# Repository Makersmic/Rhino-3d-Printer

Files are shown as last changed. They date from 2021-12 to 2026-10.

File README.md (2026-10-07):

<p align="center">
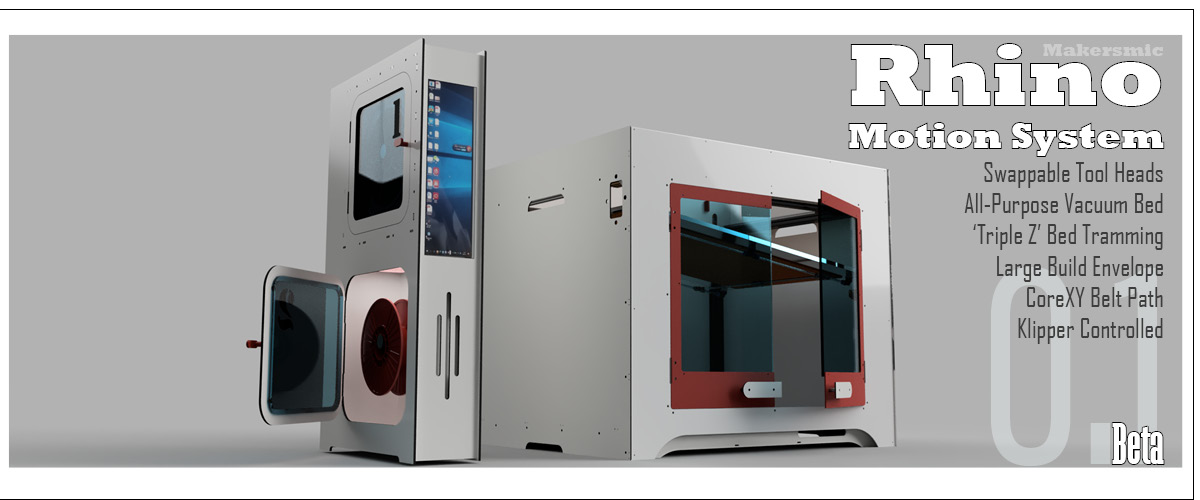
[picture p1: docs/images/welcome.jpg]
Rhino Motion System
  
</p>

<h1 align="center">Rhino Motion System</h1>

<p align="center">
  <b>An open-source, multi-tool CoreXY machine for 2D and 3D making.</b><br>
  One gantry, five swappable toolheads - 3D printing, laser, CNC spindle and drag knife - controlled by Klipper.
</p>

<p align="center">
  
  
  
  
</p>

<p align="center">
  <b>This repo:</b> the machine - CAD, drawings and build notes &nbsp;·&nbsp;
  <b><a href="https://github.com/Makersmic/Toolhead_Manager">Toolhead_Manager</a>:</b> the software - Klipper config, macros, portal and user manual
</p>

## The toolheads

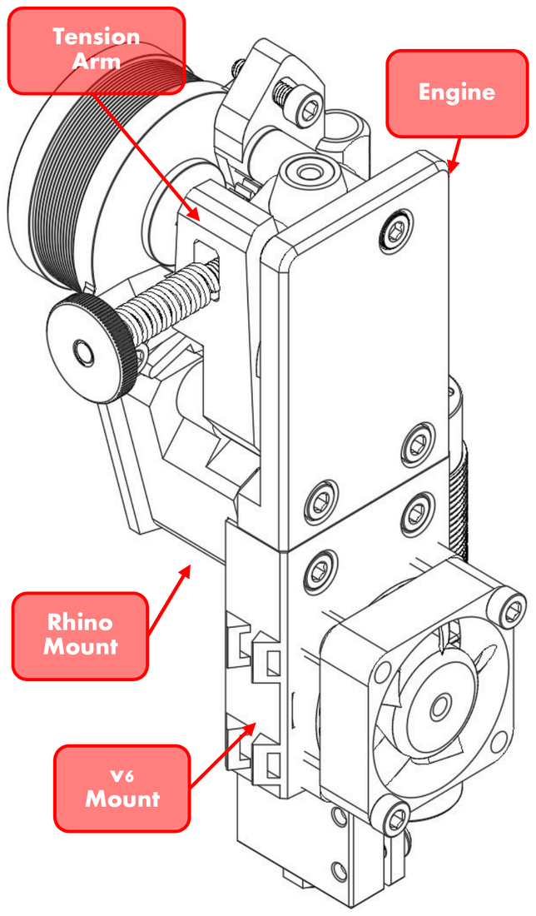
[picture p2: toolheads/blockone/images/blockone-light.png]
blockone
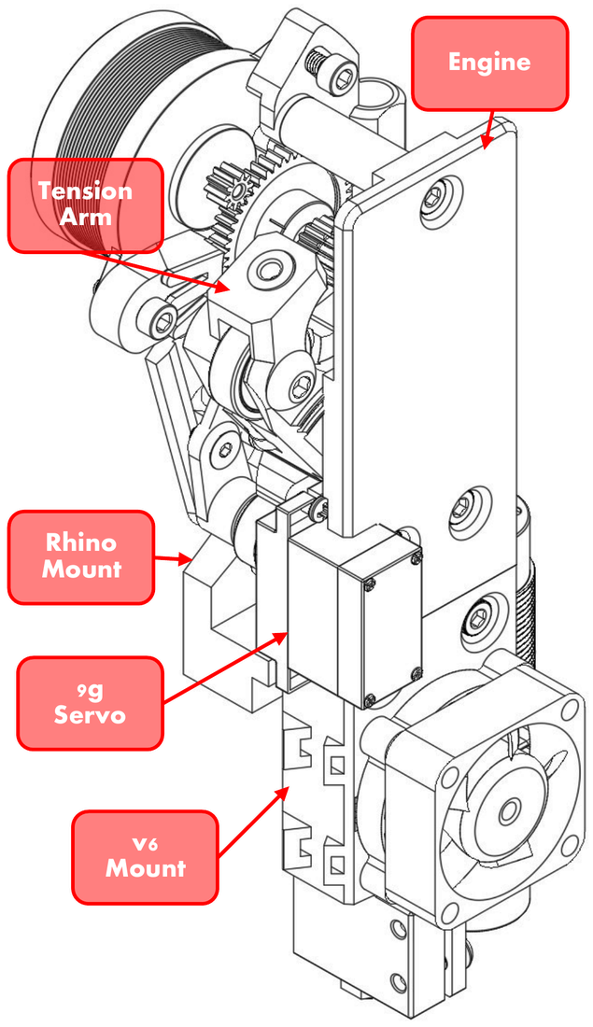
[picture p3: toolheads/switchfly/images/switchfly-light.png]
switchfly
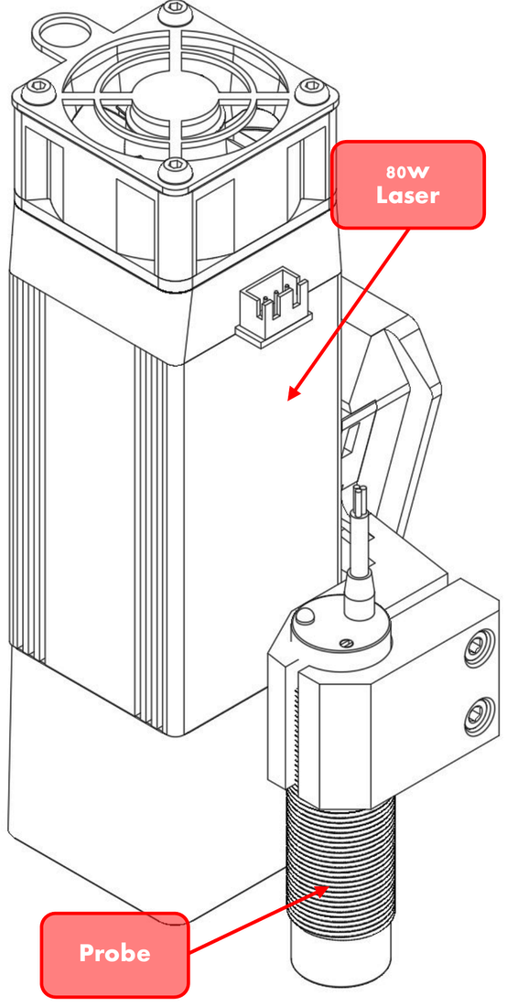
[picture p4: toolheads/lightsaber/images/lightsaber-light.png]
lightsaber
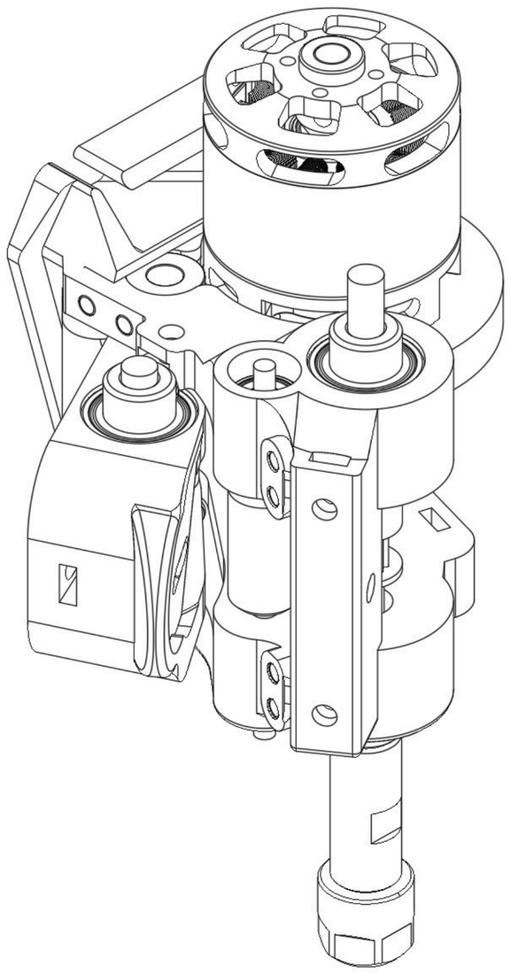
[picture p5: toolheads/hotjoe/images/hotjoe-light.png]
hotjoe
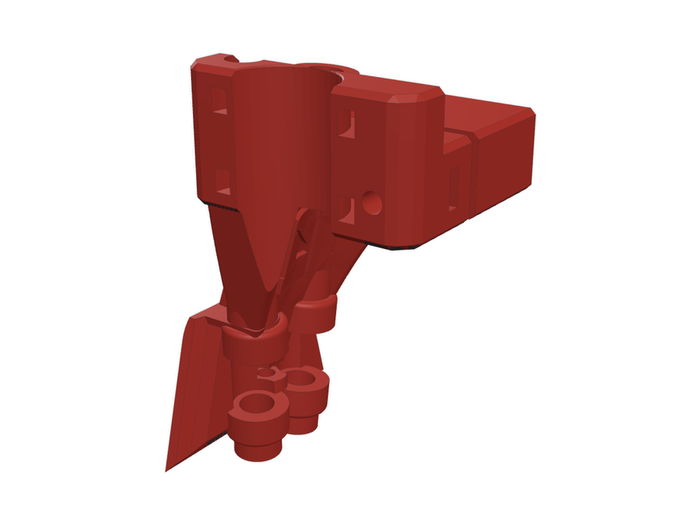
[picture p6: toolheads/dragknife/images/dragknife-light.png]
dragknife
<table align="center"><tr><td align="center"><a href="toolheads/blockone/"><picture><source media="(prefers-color-scheme: dark)" srcset="toolheads/blockone/images/blockone-dark.png"></picture></a></td><td align="center"><a href="toolheads/switchfly/"><picture><source media="(prefers-color-scheme: dark)" srcset="toolheads/switchfly/images/switchfly-dark.png"></picture></a></td><td align="center"><a href="toolheads/lightsaber/"><picture><source media="(prefers-color-scheme: dark)" srcset="toolheads/lightsaber/images/lightsaber-dark.png"></picture></a></td><td align="center"><a href="toolheads/hotjoe/"><picture><source media="(prefers-color-scheme: dark)" srcset="toolheads/hotjoe/images/hotjoe-dark.png"></picture></a></td><td align="center"><a href="toolheads/dragknife/"><picture><source media="(prefers-color-scheme: dark)" srcset="toolheads/dragknife/images/dragknife-dark.png"></picture></a></td></tr><tr><td align="center"><a href="toolheads/blockone/"><b>BlockOne</b></a><br><sub>3D printing</sub></td><td align="center"><a href="toolheads/switchfly/"><b>SwitchFly</b></a><br><sub>Dual extrusion</sub></td><td align="center"><a href="toolheads/lightsaber/"><b>LightSaber</b></a><br><sub>80 W laser</sub></td><td align="center"><a href="toolheads/hotjoe/"><b>HotJoe</b></a><br><sub>CNC spindle</sub></td><td align="center"><a href="toolheads/dragknife/"><b>DragKnife</b></a><br><sub>Drag knife</sub></td></tr></table>

Tools slot into a V-groove on the X-carriage and plug into a 21-pin umbilical at the back of the frame, so each tool
carries only the wiring it needs. [More about the toolheads and the umbilical &rarr;](toolheads/)

## Key features

- **Swappable toolheads** with one M3 bolt and a 21W4 umbilical connector
- **CoreXY with 15 mm belts** on X and Y, and the "Bulkup" XY joiners
- **Three-point Z** - three belt-driven leadscrews with kinematic couplings, trammed by Klipper
- **All-purpose vacuum bed** with air-gap insulated heated plate
- **Enclosed build chamber** with ACP panels and doors
- **Fresh air** - part cooling for printing, blow-air for the laser, chip clearing for the spindle
- **Klipper firmware** on a BTT Octopus, with DIN-rail relays for every heavy load
- **Tool Manager portal** - safe tool swaps, a page for every tool and maintenance tracking ([Toolhead_Manager](https://github.com/Makersmic/Toolhead_Manager))

<p align="center"><a href="https://github.com/Makersmic/Toolhead_Manager">Tool Manager dashboard</a><br>
<sub>The Tool Manager portal, from <a href="https://github.com/Makersmic/Toolhead_Manager">Toolhead_Manager</a></sub></p>

## What's in this repo

| Folder | What's there |
|---|---|
| [frame](frame/) | Frame assembly (2020/2040/2060 extrusion and flat bar), drawing, STEP; [panels](frame/panels/) - ACP enclosure, doors, front spacers |
| [motion/xy](motion/xy/) | XY joiners, [X-carriage](motion/xy/x-carriage/), stepper mounts, rear idler, belt tensioners, router templates |
| [motion/z](motion/z/) | Leadscrew carriages and Z stepper mounts |
| [bed](bed/) | Vacuum bed heat spreader |
| [toolheads](toolheads/) | [BlockOne](toolheads/blockone/), [SwitchFly](toolheads/switchfly/), [LightSaber](toolheads/lightsaber/), [HotJoe](toolheads/hotjoe/), [DragKnife](toolheads/dragknife/), and the legacy [Jack Rabbit](toolheads/jack-rabbit/) |
| [electrical](electrical/) | Controller, relays, distribution, umbilical and wiring diagrams |
| [filament-box](filament-box/) | "Cheeky Monkey" roll stand and runout switch (unfinished) |
| [docs](docs/) | [Software](docs/apps.md), [safety](docs/safety.md), [maintenance](docs/maintenance.md), [welcome page PDF](docs/rhino-welcome-page.pdf) |
| [archive](archive/) | 2023 firmware and app notes, kept for reference only |

**Software, config and the user manual** are in **[Toolhead_Manager](https://github.com/Makersmic/Toolhead_Manager)**: the Klipper/Mainsail config package
with a menu installer, the Tool Manager portal, OrcaSlicer profiles and the full user manual (PDF).

## Roadmap

- **BlockOne build files** - [folder ready](toolheads/blockone/)
- **SwitchFly build files**
- **Touch-probe Z setting** for the laser, spindle and drag knife
- **Kiri:Moto** for laser, drag-knife and CNC jobs from one interface
- **Project "Cheeky Monkey"** - a modular filament box: filament monitoring, air handling, chip exhaust, liquid cooling
- **Smoke detection** wired into Klipper ([safety](docs/safety.md))
- **Machine profiles** so other builders can use the Tool Manager on their own machines
- **Small build-farm management**

This is an ever-evolving project. Expect updates as parts are improved or corrected.

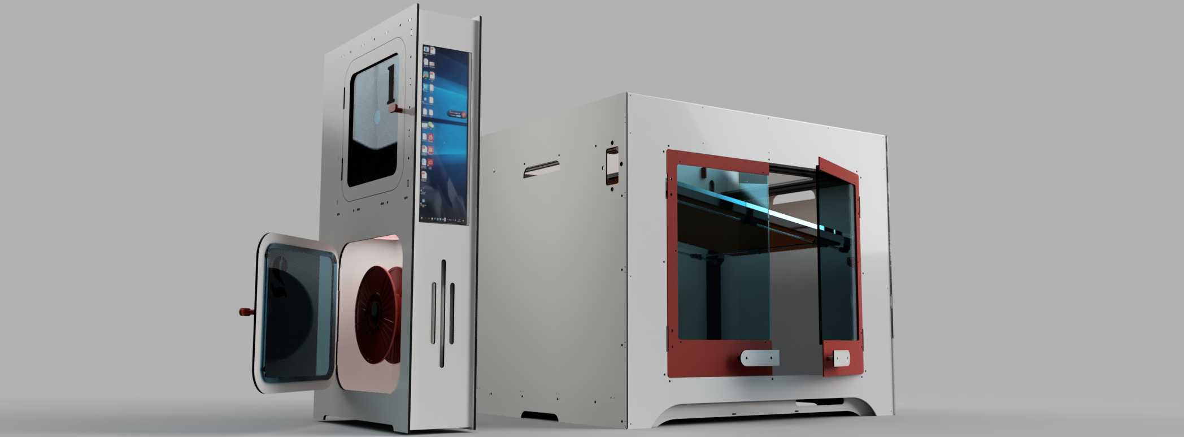
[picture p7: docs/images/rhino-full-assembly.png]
Rhino full assembly


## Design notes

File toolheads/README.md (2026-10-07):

# Toolheads

<table><tr><td align="center"><a href="blockone/"><picture><source media="(prefers-color-scheme: dark)" srcset="blockone/images/blockone-dark.png">blockone</picture></a></td><td align="center"><a href="switchfly/"><picture><source media="(prefers-color-scheme: dark)" srcset="switchfly/images/switchfly-dark.png">switchfly</picture></a></td><td align="center"><a href="lightsaber/"><picture><source media="(prefers-color-scheme: dark)" srcset="lightsaber/images/lightsaber-dark.png">lightsaber</picture></a></td><td align="center"><a href="hotjoe/"><picture><source media="(prefers-color-scheme: dark)" srcset="hotjoe/images/hotjoe-dark.png">hotjoe</picture></a></td><td align="center"><a href="dragknife/"><picture><source media="(prefers-color-scheme: dark)" srcset="dragknife/images/dragknife-dark.png">dragknife</picture></a></td></tr><tr><td align="center"><a href="blockone/"><b>BlockOne</b></a><br><sub>3D printing</sub></td><td align="center"><a href="switchfly/"><b>SwitchFly</b></a><br><sub>Dual-extrusion printing</sub></td><td align="center"><a href="lightsaber/"><b>LightSaber</b></a><br><sub>Laser</sub></td><td align="center"><a href="hotjoe/"><b>HotJoe</b></a><br><sub>CNC spindle</sub></td><td align="center"><a href="dragknife/"><b>DragKnife</b></a><br><sub>Drag knife</sub></td></tr></table>

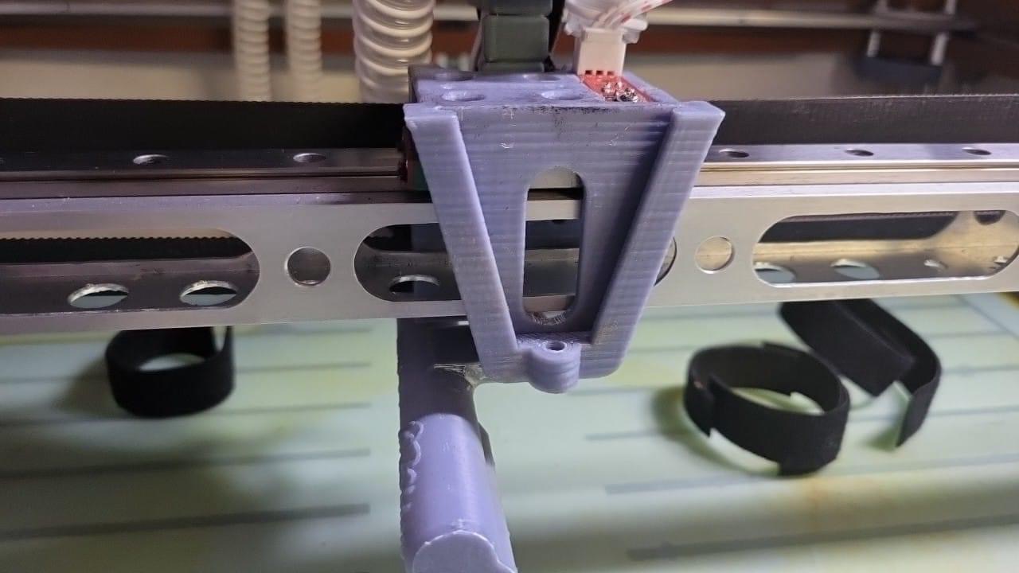
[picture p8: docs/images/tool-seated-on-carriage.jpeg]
A tool seated on the X-carriage


The Rhino uses swappable tools mounted to the X-carriage. A tool slides down into the V-groove on the front of the
carriage, which aligns it, and is held by one M3×50 bolt with a knurled nut (or wing nut).

| Slot | Tool | What it does | Folder |
|---|---|---|---|
| 1 | **BlockOne** | Single-extruder 3D printing (0.4 / 0.8 mm nozzles) | [blockone](blockone/) |
| 2 | **SwitchFly** | Two filaments, one stepper, one nozzle | [switchfly](switchfly/) |
| 3 | **LightSaber** | 80 W, 12 V blue diode laser - cutting and engraving | [lightsaber](lightsaber/) |
| 4 | **HotJoe** | 24 V brushless spindle with ER8 collet | [hotjoe](hotjoe/) |
| 5 | **DragKnife** | Passive drag knife for vinyl, cardstock, foam | [dragknife](dragknife/) |
| - | Jack Rabbit | Earlier print head, superseded by BlockOne | [jack-rabbit](jack-rabbit/) |

More tools (hot wire, needle cutter, pens, extra nozzle sizes) can be added from the
[Tool Manager](https://github.com/Makersmic/Toolhead_Manager) portal without editing config files.

## The umbilical and the Hub

Every tool ends in a male **21W4 D-sub** connector (four high-current contacts plus seventeen signal pins). The female
half is fixed at the top rear of the frame, with the **Hub** - a row of Wago-style terminal blocks - directly below it in
the cabinet. Because the mating point is at the rear, each tool carries only the wiring it needs.

| Contacts | Print heads | LightSaber | HotJoe | DragKnife |
|---|---|---|---|---|
| 1-2 | Hotend heater | - | - | - |
| 3-4 | Thermistor | Thermistor | Thermistor | Thermistor |
| 5-6 | Hotend fan | - | - | - |
| 7-10 | Extruder stepper | - | - | - |
| 11-12 | (SwitchFly: servo power) | - | 24 V power (relay) | - |
| 13-15 | Probe | Probe | Probe | Probe |
| 16-17 | - | Laser PWM | - | - |
| 18-19 | (SwitchFly: servo PWM) | - | Spindle PWM (ESC) | - |
| 20-21 | - | 12 V power (relay) | - | - |

**Constant connections** don't go through the umbilical; they run to the carriage through the Back Bone: X endstop
(3 wires), two 20 mm air tubes, the chamber thermistor and the LED strip.

### Why every tool has a thermistor

Klipper's extruder expects a temperature reading at all times. Rather than editing `printer.cfg` for every tool, each
tool carries the same thermistor type on contacts 3-4 (the laser's is on its heatsink). The swap wizard also reads it
to confirm the umbilical is seated.

## Swapping tools

Run `SWAP_TOOL` (a Mainsail button). It cools down, lowers the bed to a safe height, homes X/Y only - never Z with a
laser, spindle or knife on - and walks you through the swap with pop-ups. Sliced files name the tool they need, and a
job won't start if a different tool is mounted.

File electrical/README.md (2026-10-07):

# Electrical

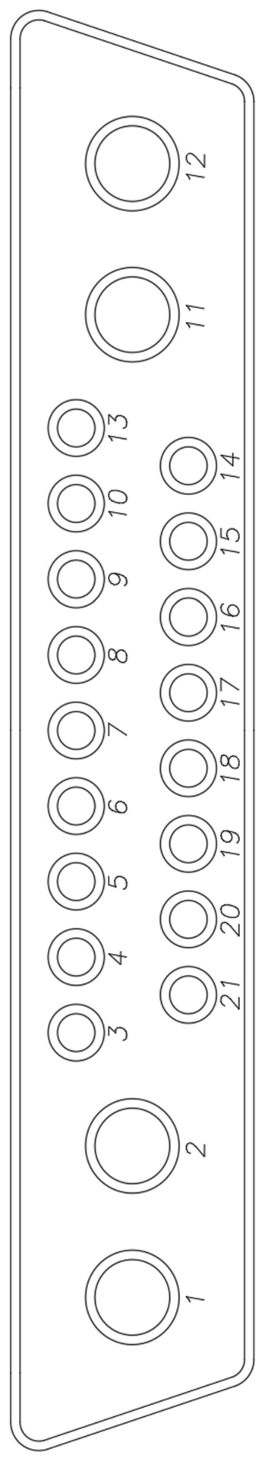
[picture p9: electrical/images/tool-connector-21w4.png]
21W4 connector
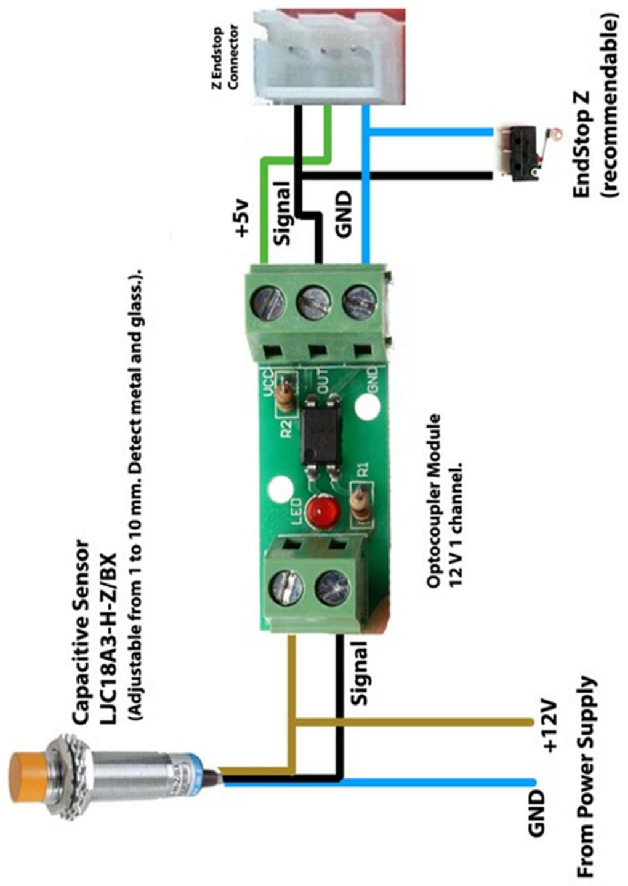
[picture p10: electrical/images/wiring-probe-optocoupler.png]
Probe wiring
<p align="center">&nbsp;&nbsp;</p>

## Controller

| Part | Current hardware |
|---|---|
| Mainboard | **BTT Octopus v1.1** (replaced the SKR GTR + M5 used in the 2023 build) |
| Klipper host | Raspberry Pi running Klipper, Moonraker and Mainsail |
| Power | Separate 24 V, 12 V and 5 V supplies |

The pin numbers for every tool are in the [toolhead pages](../toolheads/) and in the user manual in
[Toolhead_Manager](https://github.com/Makersmic/Toolhead_Manager). The old pin-assignment PDF for the GTR board has been removed.

## Relays

DIN-rail relays switch every heavy load, which keeps high currents off the board and makes a failed relay a quick
swap. Mechanical relays are easier to troubleshoot, and the click is reassuring; the heated bed mats use SSRs.

| Circuit | Relay |
|---|---|
| 12 V low current: LED and NeoPixel lighting, fans | 700-TBR24 6 A |
| 12 V high current: laser module, vacuum pump | JQX-13FL 10 A |
| 24 V high current: spindle (ESC power) | JQX-38F 40 A |
| Heated bed mats | Solid-state relays |

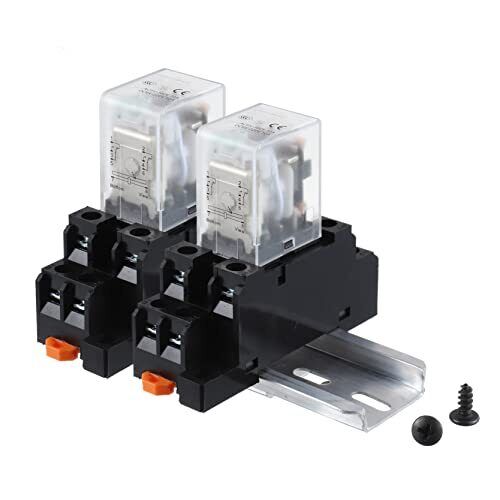
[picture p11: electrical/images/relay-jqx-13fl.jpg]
JQX-13FL relay
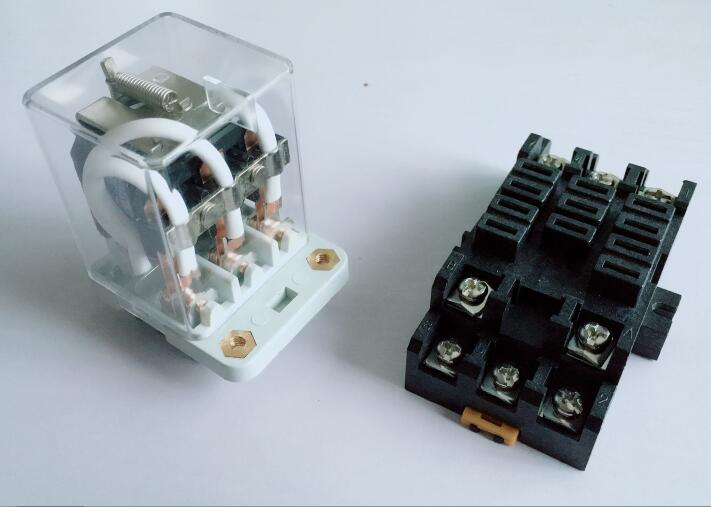
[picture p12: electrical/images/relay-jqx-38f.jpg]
JQX-38F relay


## Distribution and protection

- **Umbilical interface (the Hub):** Wago-style blocks that can't be bridged.
- **Power distribution:** traditional distribution blocks that can be bridged.
- **DIN-rail fuse holders:** protect the stepper motor lines against shorts.

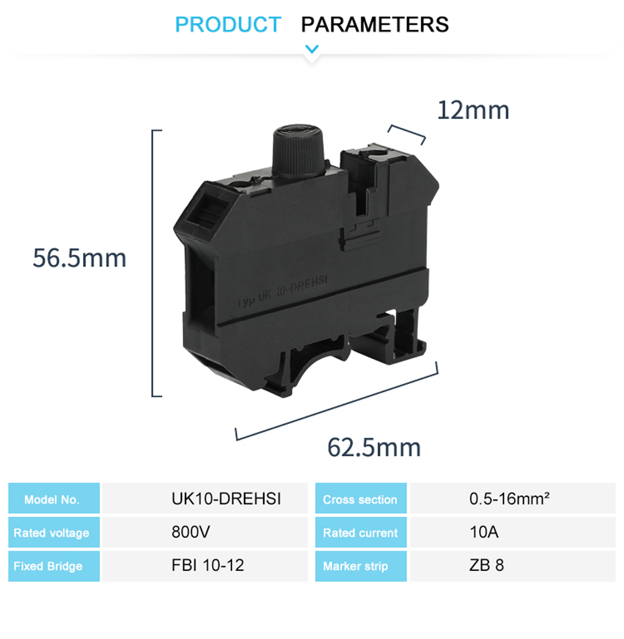
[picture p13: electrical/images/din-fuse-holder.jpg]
DIN-rail fuse holder
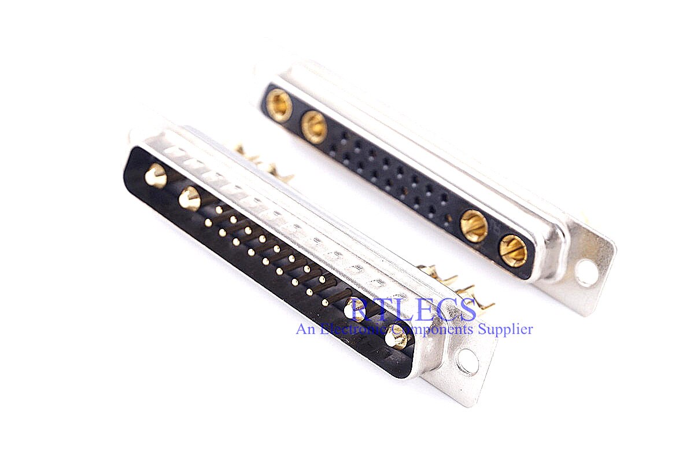
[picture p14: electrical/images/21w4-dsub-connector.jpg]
21W4 D-sub connector


## Umbilical

Male/female **21W4 D-sub** connectors; the cable is braided Cat5 plus two 14 AWG conductors. See
[toolheads](../toolheads/#the-umbilical-and-the-hub) for what each contact carries.

## Wiring diagrams

| Diagram | |
|---|---|
| Capacitive Z probe through the optocoupler (mounted in the cabinet) | [wiring-probe-optocoupler.png](images/wiring-probe-optocoupler.png) |
| 4-pin PWM fan | [wiring-4pin-fan.png](images/wiring-4pin-fan.png) |
| HotJoe ESC | [wiring-hotjoe-esc.png](images/wiring-hotjoe-esc.png) |
| SwitchFly servo | [wiring-switchfly-servo.png](images/wiring-switchfly-servo.png) |

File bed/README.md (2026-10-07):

# Vacuum bed

The Rhino's all-purpose vacuum bed. The heated build plate uses 'air gap' insulation: an open pocket of air between the
silicone heater mats and the cover on the underside.

| File | What it is |
|---|---|
| `Heat Spreader.step` | Bed heat spreader |

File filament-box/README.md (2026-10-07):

# Cheeky Monkey - the filament box

> **Unfinished design.**
An unfinished design, Cheeky Monkeys initial putpose was to provide monitoring and filament splices during 3d printing or other manufacturing procedures but was subsequently halted when the realization came that Cheeky Monkey needed to evolve into something much more in order to support future tool heads or manufacturing techniques.  
Cheeky Monkeys future goals will be to support 3d printing filament monitoring, an air handling system for high pressure blow air accessories and too heads, deep vacuum for chip removal and vacuum forming.

| File | What it is |
|---|---|
| `Roll Stand v5.step` | Filament roll stand |
| `Filament Runout Swich v5.step` | Filament runout switch |

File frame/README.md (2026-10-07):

## The Frame

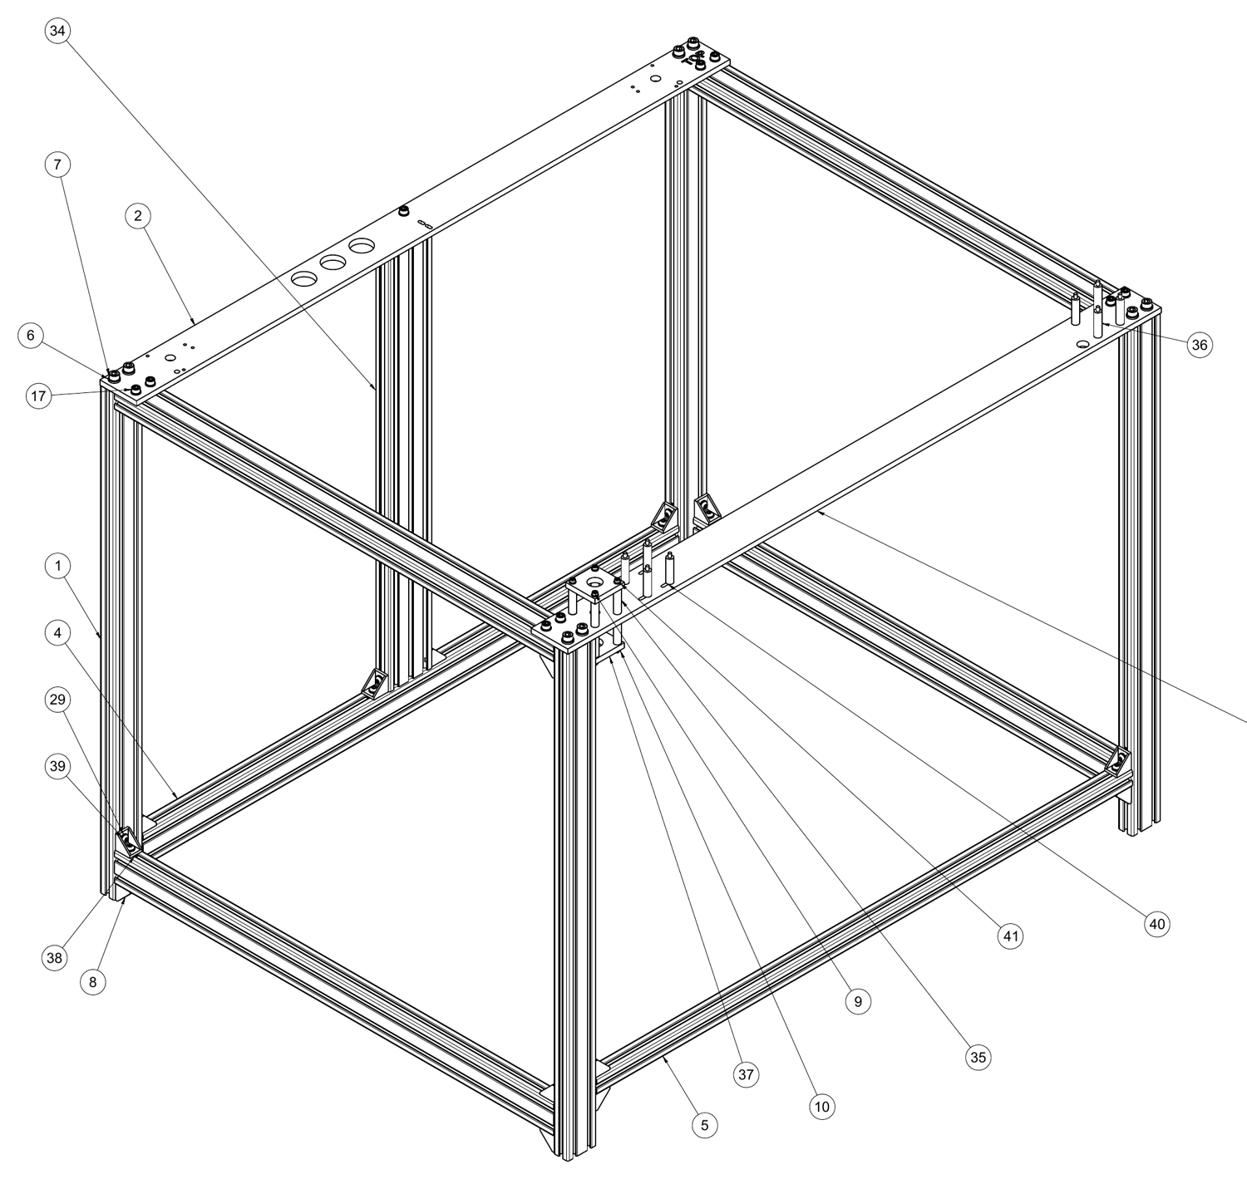
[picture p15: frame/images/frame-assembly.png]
Frame assembly

The Rhino utilizes aluminum extrusions based on the popular 2020, 2040, 2060 specification and 0.25" x 2" aluminum flat bar among other standard fasteners.  

### Designed for DIY
I took an uncommon approach with the aluminum flat bar components in the sense that you will find some components directly mounted to them.  To keep hole placement and 
other features accurate I have designed up 3d printable templates for hole placement and other features such as large pass-through cut-outs.  

Templates can be simply clamped to the workpiece and then a user may use a cordles drill or router for the appropriate feature.  When using a router, load a 0.375" 
flush trim bit with plenty of cutting fluid.  Also, due to possible excessive heat i recommend ABS as the material choice when 3d printing the templates.  Tutorial videos may be found on youtube of several people utuilizing a router for cutting aluminum.  It is recommeneded 
to watch a couple if you are unfamiliar with this technique.

### Parts List
Refer to `Frame Assembly Drawing v1.pdf` for a complete parts list of the frame and assembly reference.  

### Use socket-head bolts
Use Hex-Socket head style bolts, not Button head style bolts.  Button head style bolts have a greater tendancy to strip-out when being torqued down.

### Enclosure panels
3 mm ACP panels, doors and hinges, and the front spacer assembly are in [panels](panels/).

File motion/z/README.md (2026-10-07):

# Z axis

The bed rides on **three leadscrews** joined to the build plate by kinematic couplings: one **T12×2** at the rear and
two **T8×2** at the front. Each screw has its own stepper and is belt-driven through a **2:1 reduction** on closed-loop
2GT 15 mm belts (180–190 mm loop).

Klipper matches this with `gear_ratio: 2:1` on all three Z steppers (`stepper_z`, `stepper_z1`, `stepper_z2` in
`printer.cfg`). Because each corner has its own motor, Klipper trams the bed with `Z_TILT_ADJUST`.

Parts are in [leadscrew-based](leadscrew-based/).

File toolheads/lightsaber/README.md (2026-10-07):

# LightSaber

<p align="center"><picture><source media="(prefers-color-scheme: dark)" srcset="images/lightsaber-dark.png">lightsaber</picture></p>

**Laser cutting and engraving** · slot 3 in the Tool Manager

An 80 W, 12 V blue diode laser for cutting vector shapes from flat sheet and engraving. A relay switches its 12 V
supply (contacts 20-21) and Klipper drives its intensity (contacts 16-17). A thermistor on the heatsink keeps Klipper
happy and lets the swap wizard confirm the umbilical is seated. The printed **height gauge** sets the focus distance.

**Safety:** wear glasses rated for the laser's wavelength, run extraction, never cut PVC or vinyl, and stay with the
machine for the whole cut.

## Files

| File | What it is |
|---|---|
| `Laser Mount.step` | Mount that slots onto the X-carriage |
| `Height Gage.step` | Printed gauge for setting focus height |

## Tool connector (21W4)

Contacts this tool uses. Pins 1, 2, 11 and 12 are the high-current contacts. Full wiring: [electrical](../../electrical/).

| Contact | Use |
|---|---|
| 3 | Thermistor |
| 4 | Thermistor |
| 13 | Probe |
| 14 | Probe |
| 15 | Probe |
| 16 | Laser PWM (5 V) |
| 20 | + 12 V power activate |
| 21 | - 12 V power activate |

## Running it

- **Set up a job with:** `LASER_JOB_SETUP FILE=<name>.gcode`
- **Outputs in Klipper:** LASER_INITIALIZE 12 V rail, SERVO_LASER intensity
- **Macros:** `LASER_JOB_SETUP`, `LASERHOME`, `LASER_FOCUS_ALIGN`, `SET_LASER_POWER`, `ACTIVATE_LASER`, `DEACTIVATE_LASER`

Config, macros and the Tool Manager portal live in **[Toolhead_Manager](https://github.com/Makersmic/Toolhead_Manager)**; the user manual there has a full chapter on each tool.

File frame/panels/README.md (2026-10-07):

## Panels
Panels are to be constructed using material 3mm in thickness, ACP is the recommended material choice.

| Folder | What's there |
|---|---|
| (this folder) | Inner and outer panels, control panel, side panels |
| [door-hardware](door-hardware/) | Doors, hinges and hinge pin |
| [front-spacer-assembly](front-spacer-assembly/) | Front spacers, corner bracket and drawing |

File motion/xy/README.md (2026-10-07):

# The Gantry
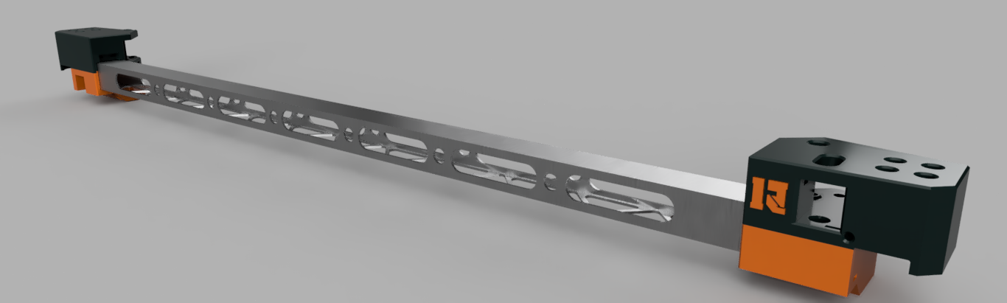
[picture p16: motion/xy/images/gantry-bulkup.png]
Rhino Motion System


## XY Motion System
Optimized for 15mm belts, the files found within this section will enable you to construct the xy motion system.  As a bonus I've uploaded step files to make editing for modifications easier for the community.

### DIY Aluminum Gantry Frame
The x-axis frame piece is constructed using 1" aluminum square tube with a wall thickness of 1/16".  Cutouts are made using 3d printed router templates.  Templates and how to use them: [gantry-router-templates.md](gantry-router-templates.md).
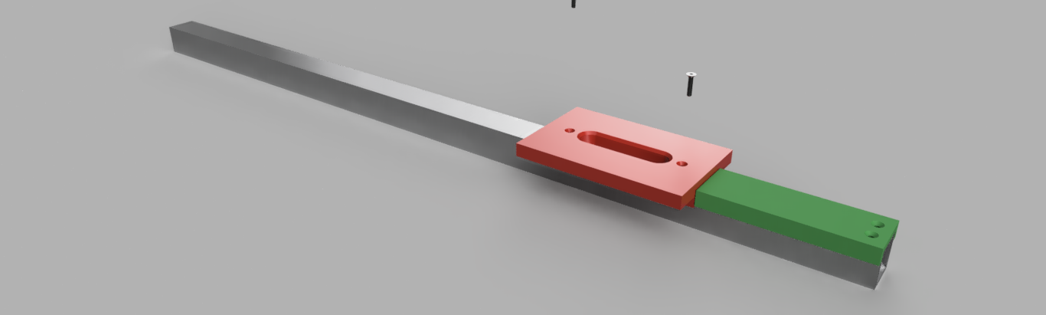
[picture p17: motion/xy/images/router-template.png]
Rhino Motion System


### Why 15mm belts?
Because of the tools that can be used with the Rhino motion system, I felt it best to go with some hefty belts.  In additional to a longer duty cycle benefits of these larger belts would include less resonance 
on the gantry which translates to higher quality 3d prints, smoother cuts when using the laser or spindle modules, and a quieter printer.

### How long should the belts be?
3 meters for each belt run, so 6 meters total will be needed.  It is also recommended to utilize dust-proof glass fiber core belts.

### Change History - new section
04-14-2023 - Uploaded a new design for the xy joiners, a design that I refer to as "The Bulkup Concept".  This came about after i began to notice sagging in previous design where the x-axis frame and xy joiner meet.  In addition I added extra material to the areas that contain the pulleys to account for excessive strain during belt tensioning.  This design has been tested for 3 months and is proving effective.

## In this folder

| Folder | What's there |
|---|---|
| (this folder) | XY joiners (left/right, top/bottom), Y endstop flag |
| [x-carriage](x-carriage/) | Carriage, Back Bone mount and bearing spacer |
| [stepper-mounts](stepper-mounts/) | A/B stepper mounts and Torque Buddy |
| [rear-center-idler](rear-center-idler/) | 15 mm rear centre idler and drawing |
| [belt-tensioner](belt-tensioner/) | Belt tensioner, cam and knob assemblies with drawings |

<p align="center">Gantry</p>

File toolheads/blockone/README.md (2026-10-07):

# BlockOne

<p align="center"><picture><source media="(prefers-color-scheme: dark)" srcset="images/blockone-dark.png">blockone</picture></p>

**3D printing - single extruder** · slot 1 in the Tool Manager

BlockOne is the Rhino's single-extruder print head and the updated version of the
[Jack Rabbit](../jack-rabbit/). It uses an E3D v6 Volcano hotend at 24 V with a BMG drive gear for 1.75 mm filament,
with OrcaSlicer profiles for 0.4 mm and 0.8 mm nozzles. Part cooling comes from the Rhino's universal blow-air system.

## Files

> **Build files coming soon.** This folder is ready for BlockOne's STEP/STL files and drawings - upload them here.
> Until then, the [Jack Rabbit](../jack-rabbit/) files show the earlier design.

## Tool connector (21W4)

Contacts this tool uses. Pins 1, 2, 11 and 12 are the high-current contacts. Full wiring: [electrical](../../electrical/).

| Contact | Use |
|---|---|
| 1 | 24 V hotend |
| 2 | 24 V hotend |
| 3 | Thermistor |
| 4 | Thermistor |
| 5 | 24 V hotend fan |
| 6 | 24 V hotend fan |
| 7 | Stepper |
| 8 | Stepper |
| 9 | Stepper |
| 10 | Stepper |
| 13 | Probe |
| 14 | Probe |
| 15 | Probe |

## Running it

- **Set up a job with:** `Slicer start G-code (START_JOB)`
- **Outputs in Klipper:** Hotend heater, hotend fan, part-cooling fan
- **Macros:** `NOZZLE_HEIGHT_CALIBRATE`, `PRIME_LINE`, `PURGE`, `FILAMENT_CHANGE`, `CALCULATE_PA`

Config, macros and the Tool Manager portal live in **[Toolhead_Manager](https://github.com/Makersmic/Toolhead_Manager)**; the user manual there has a full chapter on each tool.

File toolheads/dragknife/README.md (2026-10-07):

# DragKnife

<p align="center"><picture><source media="(prefers-color-scheme: dark)" srcset="images/dragknife-dark.png">dragknife</picture></p>

**Drag-knife cutting - vinyl, cardstock, thin foam** · slot 5 in the Tool Manager

A passive tool (formerly *Ostrich*) for Roland No. 9 and No. 10 blade holders. It has no power output: cut depth
comes from the blade dial and the Z zero set in the job wizard.

## Files

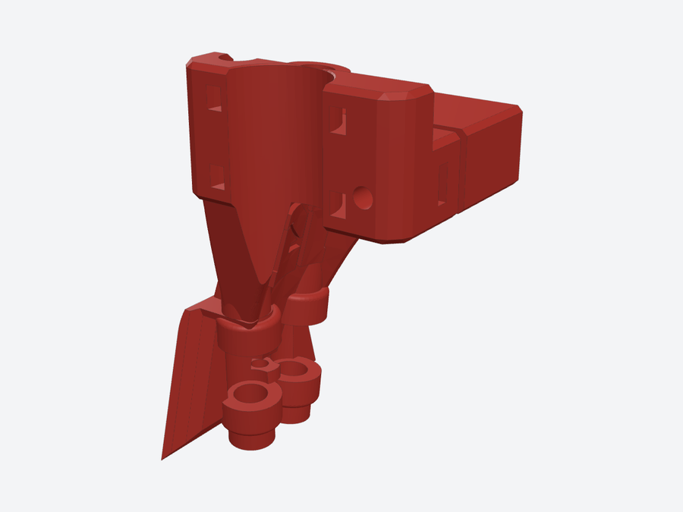
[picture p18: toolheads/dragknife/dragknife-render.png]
DragKnife render


| File | What it is |
|---|---|
| `Ostrich Drag Knife.step` | Drag-knife holder |

## Tool connector (21W4)

Contacts this tool uses. Pins 1, 2, 11 and 12 are the high-current contacts. Full wiring: [electrical](../../electrical/).

| Contact | Use |
|---|---|
| 3 | Thermistor |
| 4 | Thermistor |
| 13 | Probe |
| 14 | Probe |
| 15 | Probe |

## Running it

- **Set up a job with:** `DRAGKNIFE_JOB_SETUP FILE=<name>.gcode`
- **Outputs in Klipper:** None (passive tool)
- **Macros:** `DRAGKNIFE_JOB_SETUP`

Config, macros and the Tool Manager portal live in **[Toolhead_Manager](https://github.com/Makersmic/Toolhead_Manager)**; the user manual there has a full chapter on each tool.

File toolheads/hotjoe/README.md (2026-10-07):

# HotJoe

<p align="center"><picture><source media="(prefers-color-scheme: dark)" srcset="images/hotjoe-dark.png">hotjoe</picture></p>

**CNC spindle - light engraving and milling** · slot 4 in the Tool Manager

A brushless motor (2814, 1000 kV) with an ER8 collet, driven by an 80 A HobbyWing ESC on 24 V. A 40 A relay
powers the ESC only while the spindle is in use; the speed signal runs at 400 Hz. Intended for light-duty work -
check real speeds at the collet with a tachometer before relying on them, and calibrate the ESC once with
`CALIBRATE_ESC`.

## Files

| File | What it is |
|---|---|
| `Spindle Assembly.step` | Complete spindle assembly |
| `Spindle Main Body.step`, `Main Body Mount Clip v2.step`, `Spindle Carriage Mount Clip.step` | Body and carriage mounting |
| `Tensioner Body.step`, `Tension Arm Shield.stl` | Belt drive tensioner |
| `Motor Shield.step`, `Gearbox Shield.step` | Safety covers |
| `70mm cnc brush holder.step` | Brush skirt for dust collection |
| `Blow Air Clip v1.step`, `turbine.stl` | Blow-air nozzle |

## Tool connector (21W4)

Contacts this tool uses. Pins 1, 2, 11 and 12 are the high-current contacts. Full wiring: [electrical](../../electrical/).

| Contact | Use |
|---|---|
| 3 | Thermistor |
| 4 | Thermistor |
| 11 | 24 V relay power |
| 12 | 24 V relay power |
| 13 | Probe |
| 14 | Probe |
| 15 | Probe |
| 18 | PWM |

## Running it

- **Set up a job with:** `CNC_JOB_SETUP FILE=<name>.gcode`
- **Outputs in Klipper:** Spindle_power relay, SPINDLE_SPEED ESC signal
- **Macros:** `CNC_JOB_SETUP`, `SET_WORK_ZERO`, `PROBE_Z_WORK_ZERO`, `G54`, `Spindle_ACTIVATE`, `Spindle_DEACTIVATE`, `CALIBRATE_ESC`

Config, macros and the Tool Manager portal live in **[Toolhead_Manager](https://github.com/Makersmic/Toolhead_Manager)**; the user manual there has a full chapter on each tool.

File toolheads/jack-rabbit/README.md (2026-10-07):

# Jack Rabbit (legacy)

> **Outdated - superseded by [BlockOne](../blockone/).** Kept for reference and for anyone who built one.

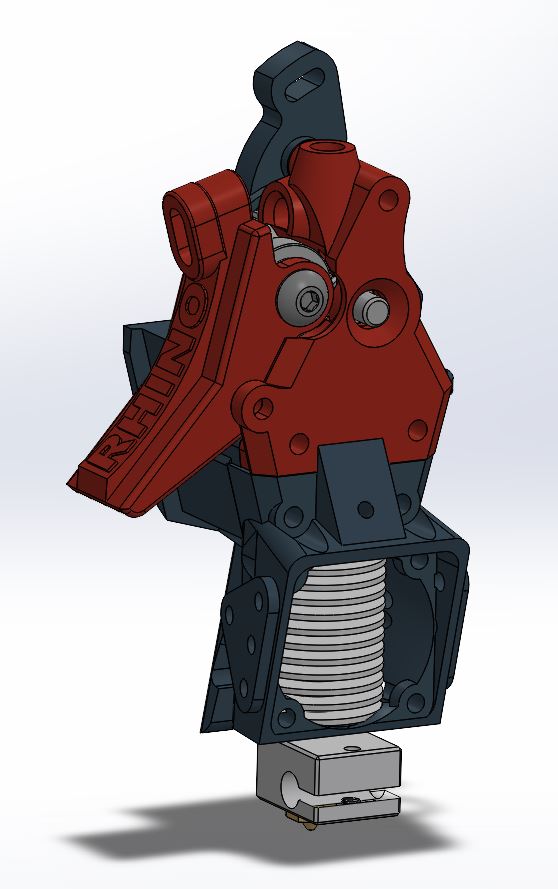
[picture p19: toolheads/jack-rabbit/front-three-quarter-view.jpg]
Jack Rabbit


## Lightweight direct-drive 3D printing tool head
The Jack Rabbit utilizes the large drive gear and a single famous 'BMG' gear in combination with a 625zz bearing to feed filament to the nozzle.  Gears are driven by round body style nema 14 stepper motor with a 10 tooth gear.  Print speeds can be had at 200mm in conjunction with an E3D v6 volcano hotend.  

## Key features
- Lightweight
- 5:1 gear ratio
- Squeeze-trigger release for easier one-handed operation
- Part cooling from a 40 mm double delta fan

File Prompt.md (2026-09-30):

📂 MASTER SPECIFICATION: THE RHINO MULTI-TOOL ECOSYSTEM
🤖 System Introduction & Context
This file serves as the definitive architecture manual and "State of the Machine" baseline for The Rhino—a heavily customized, modular 5-axis hybrid manufacturing workspace powered by Klipper, Moonraker, and an OrcaSlicer frontend. This machine utilizes a shared coordinate rail system but completely switches disciplines based on the physically attached toolhead via a manual, hot-swappable 21-pin umbilical connection line.
🗺️ Stored Global Mappings (variables.cfg)
All macros are explicitly aligned to a single, persistent disk cache file (variables.cfg) via Klipper’s [save_variables] module to prevent volatile dual-tracking sync lag across machine boots:
• Tool Registries: Stored inside a dictionary variable named tool_mapping mapping indexes (0 to 4) to names (BlockOne, SwitchFly, LightSaber, HotJoe, DragKnife).
• Active Hardware Position Tracker: The wizard uses printer["gcode_macro SWAP_TOOL"].current_tool to track what is physically connected to the machine.
• Workspace Transformations: Persistent CNC registers (cnc_g54_x, cnc_g54_y, cnc_g54_z) store offsets for subtractive tasks, safely isolating industrial coordinate shifts from default 3D print endstops.
🔧 Active Toolhead Modules & Software Rules
1. BlockOne (Slot 0)
• Type: DEPOSITION
• Configuration: Standard single-extruder 3D printing toolhead. Starts execution by passing explicit formatting via OrcaSlicer: START_JOB TOOLHEAD="BlockOne" MATERIAL="[filament_type]" NOZZLE_SIZE=[nozzle_diameter] EXTRUDER=0. Numbers are cleanly passed un-quoted to ensure stepper current arithmetic checks parse flawlessly.
2. SwitchFly (Slot 1)
• Type: DEPOSITION
• Configuration: Single physical stepper motor shared between two independent filament tubes. Alignments are shifted using a dedicated _SWITCHFLY_SET_PATH servo flag (0 to 180 degrees).
• The Direction-Reversal Override: Because path 1 pulls filament from the backside of the drive gears, G0 and G1 are globally intercepted using rawparams. If SwitchFly path 1 is active, extrusion targets are dynamically inverted to a negative orientation (E * -1.0) on the fly, safely preserving all travel tracking, layer speeds, and slicer width strings.
3. LightSaber (Slot 2)
• Type: LASER
• Configuration: High-frequency laser diode cutter. Integrates standard GRBL convention parameters (M3/M4/M5) scaled smoothly against laser_s_max.
• Safety Lockout: Implements hard hardware-gated overrides inside SET_LASER_POWER. If any job streams an M3 signal while a 3D printer hotend or spindle is attached, Klipper forces an immediate safety shutdown to protect the umbilical pins and user workspace. Isolates LEDFLASH from high-frequency lines to eliminate processor stutter. Features an interactive 1% duty-cycle visibility target utility (LASER_FOCUS_ALIGN).
4. HotJoe (Slot 3)
• Type: CNC
• Configuration: Brushless outrunner CNC spindle motor driven by a 400Hz open-loop RC Electronic Speed Controller (ESC). Low-endpoint throttle arms at 0.3, scaling to high-endpoint maximum thresholds at 1.0.
• Subtractive Calibration: Houses an interactive, graphical windowed CALIBRATE_ESC endpoints synchronization wizard. Integrates G54 offsets and an automated PROBE_Z_WORK_ZERO 10mm aluminum touch-plate downward search matrix.
5. DragKnife (Slot 4)
• Type: DRAG_KNIFE
• Configuration: Mechanical spring-loaded vector vinyl plotting blade. Features a dedicated, safety-gated absolute scoring utility (_DK_TEST_CUT) which drops exactly 0.3mm beneath the G54-zero material face to trace a 10mm validation cut line, protecting underlying cutting mats from relative plunge errors.
🖥️ Graphic User Experience Panels (Mainsail UI)
• SWAP_TOOL: A modular 2-stage hot-swap wizard. Shuts down heaters, cools gantry items to a safe 40°C, cuts extruder power lines to prevent pin-arcing, and pauses execution (PAUSE_BASE). It prompts the physical hand-swap before allowing verification hooks (CONFIRM_TOOL_INSTALL) to read the universal PF4 thermistor circuit line.
• PREHEAT: A dynamic pre-flight checker. If a sliced job specifies PLA, it halts execution and opens a web-interface modal allowing the operator to click a button and completely bypass build plate heating/soaking, leaping straight into the file.
• CNC_JOB_SETUP: A sequential step-by-step setup screen for machining. Guides workholding clamps, collet torque, and launches an optional dynamic choice path between touch-plate or manual paper zeroing.
• BACKUP_CONFIG: Automatically hooks into CONFIRM_TOOL_INSTALL and any successful print job that tracks an execution runtime greater than 2 hours (printer.print_stats.total_duration >= 7200). Packages and pushes the entire .cfg layout tree, macro sets, and uploaded OrcaSlicer .bb bundles straight to your remote GitHub repo over an authenticated secure SSH key tunnel (git_protocol="ssh").

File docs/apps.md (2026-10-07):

# Software

I use free applications wherever possible - licence fees limit development and hurt community growth.

| Job | Software | Notes |
|---|---|---|
| Firmware and control | **Klipper + Moonraker + Mainsail** | Config, macros and the Tool Manager portal are in [Toolhead_Manager](https://github.com/Makersmic/Toolhead_Manager) |
| 3D printing (BlockOne, SwitchFly) | **OrcaSlicer** | Ready-made BlockOne profiles: [`slicer/orca`](https://github.com/Makersmic/Toolhead_Manager/tree/main/slicer/orca). The start G-code calls `START_JOB TOOLHEAD=BlockOne ...` |
| Laser, drag knife, CNC | **Kiri:Moto** (planned) | Free, open-source, browser-based; covers laser, drag knife and CNC in one interface |
| Laser (2023 workflow) | LaserWeb 4 | Old setup notes kept in [archive/2023-apps](../archive/2023-apps/laserweb-setup.md) |

Laser, spindle and drag-knife jobs are started with `LASER_JOB_SETUP`, `CNC_JOB_SETUP` or `DRAGKNIFE_JOB_SETUP`
`FILE=<name>.gcode`, which check the mounted tool and walk through zeroing before the file runs.

## Other useful software

- [Inkscape](https://inkscape.org/) - vector artwork for laser and knife
- [Tinkercad](https://www.tinkercad.com/) - quick 3D models
- [Zamzar](https://www.zamzar.com/) - file conversion

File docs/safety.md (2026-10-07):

# Safety

> **In place today** (in [Toolhead_Manager](https://github.com/Makersmic/Toolhead_Manager)): tools are only swapped once the hotend and bed are below 40 °C, Z is
> never homed with a laser, spindle or knife mounted, a job won't start if the wrong tool is mounted, every tool output is
> switched off on cancel, swap or emergency stop, and added powered tools have a power cap and a watchdog timer. The smoke-detection system below is still **planned**.

## Introduction
When people in the 3d printing talk about saftey there seems to be a universal concern, fire.  In terms of the Rhino though i wanted to expand this subject out more due to the 
multiple tools that can be utilized and the change procedures revolving around those tools.  

To address fire safety i want to install smoke alarms with relays.  The purpose of the smoke alarm having a relay is that the relay can be tied into the endstop inputs of the control 
board, thus making Rhino aware of when smoke/fire occurs and further more enabling Rhino to take action.

### Smoke Detection Module:
MQ-2.....Aliexpress $10

This smoke detector can operate on 12v or 24v and is small in size,49x45x20mm

The BTT Octopus has spare endstop inputs available for these. (The 2023 notes counted inputs on the old SKR GTR + M5.)

In addition to the smoke detection modules, the printer must have 110v and 220v relays that are tied into the power supplies of the printer.  Without these killing power to the
control board or other components will not be possible.  It may also be needed to run secondary mcu to support fire protocols when the printer has been powered off.  To
take a step further i can even see this secondary mcu having it's own power source that is not tied into mains power but rathe run from a rechargeable battery pack that is constantly
charged.  Utilizing 18650 batteries in a battery pack of some kind could be an avenue traveled for this aspect.

## Anticipated zones for smoke and fire:
-Build Chamber-This sensor will be located in the lid.

-Control Cabinet-These sensors one on each side will be mounted on the same din rails as the other components.  One for each side so a total of 2 sensors, will be mounted in the middle of top
din rail.

-Build Plate-Rhino utilizes 'air gap' insulation for the heated build plate.  The open pocket of air between the silicone heated mats and the cover located on the bottom side of the plate there is clearance to be able to install a smoke detector.

-Power Supply/Power Distribution Area-This sensor would be located in the area within close proximity to the power supplies and the bank of terminal blocks acting as power 
distribution.

## Actions
The macro that is written needs to do a couple things to ensure the long life of our printer:
-Immediately or almost immediately killing power to the 3d printer.

-Storing the last position of the print head much like that of when the printer is paused.

-Informing the user that smoke has been detected though the main display, or possibly tying it into telegram bot so a user can get messages sent directly to a device that they keep on their person.

In retrospect, all of the actions described above will come with conditions, or perhaps not triggered until a requirement is met or not met.

This subject needs to be expanded upon.

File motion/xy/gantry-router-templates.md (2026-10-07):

# Gantry Router Template Usage Guide
This document is to outline the usage of the router templates used to create the cutouts found on the x-axis aluminum frame piece.

### Materials Needed
1 3d printed router template

1 3d printed drill template

1pc 1" x 36" aluminum square tube, 0.0625" wall thickness

2pc m3 x 14mm Flathead bolt

Cutting Fluid

### Tools Needed
1 Power Drill

1 Palm Router(or router of your choice

1 0.375" Diameter Flush Trim Bit(2 Flute)

1 m3 tap

1 2.8mm drill bit

1 0.4375" drill bit

Various clamps for work staging

### How-to
1.  Start by placing the 3d printed drill template as shown.  Ensure that the side surface of the template is flush against the surface of the aluminum square tube.
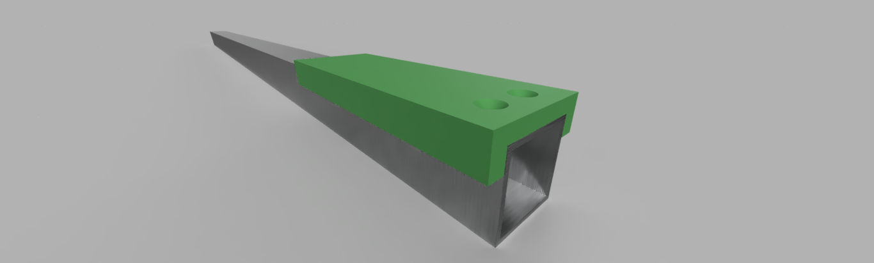
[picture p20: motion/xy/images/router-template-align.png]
Rhino Motion System


2.  Using a center punch, mark each end of the square tube using the template for placement of the center punch.  Each end of the square tube should have two markings for through-holes.
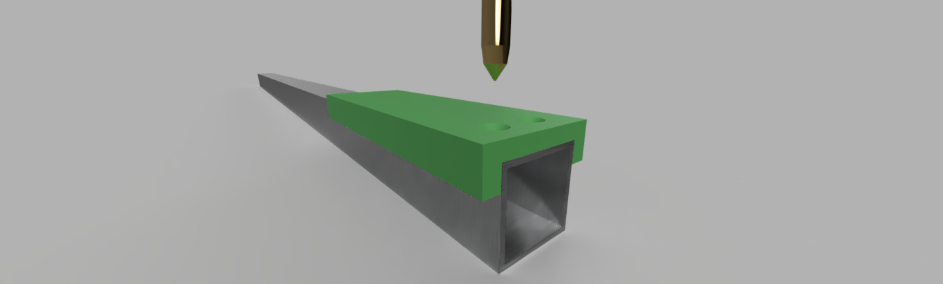
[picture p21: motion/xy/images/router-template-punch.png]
Rhino Motion System


3.  Remove the 3d printed drill template and drill each hole completely through the square tube using a 3.5mm drill bit.  It is recommended to use a drillpress when drilling these holes to ensure proper alignment.
4.  Wipe down or blow off all chip accumalations from drilling procedure.
5.  Install 3d printed router template as shown.
Rhino Motion System

6.  Mark first and second hole with center punch.
7.  Drill a hole in the cutout area using the 0.4375" drill bit.  This will be the **starting position** of where the router will begin cutting.
8.  Drill and tap first and second holes for m3 size bolt.
9.  Wipe down or blow off all chip accumalations from drilling procedure.
10.  Align the 3d printed router template to second cutout feature by means of aligning first hole of template to the second tapped hole of the aluminum square.

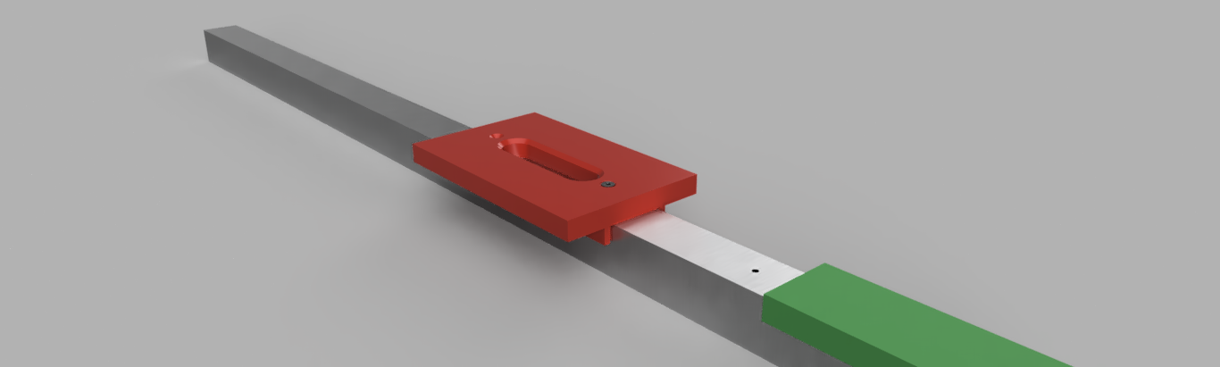
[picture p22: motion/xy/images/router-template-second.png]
Rhino Motion System


11. Secure template in place by installing an m3 flathead bolt in first alignment hole.
12.  Drill and tap second hole of template into aluminum square tube  with m3 tap.
13.  Wipe down and blow off all chip accumalations drom drilling procedure.
14.  Install second flathead bolt into second alignment hole.
15.  Repeat steps 9-14 until all cutouts have been recognized.
16   Ensure 3d printed router template in place by ensuring that the template is held in place by means of the 2 m3 flathead bolts installed into the template and square tube.
17.  With the power cord disconnected, set the depth of the 0.375" router bit to a cut depth of approximately 1/32".  
18.  Ensure cutting fluid has been applied to router bit and to the area of the square tube that will cut into by the router.
19.  With the router bit secured in the router and the cutting depth, place the router on top of the template in such a way that the router bit is in the center of the **starting position** hole.
20.  With a firm grasp on the router, power on the tool.
21.  Moving the router slowly, follow the templates cutout edge with bearing of the flush trim bit.
22.  When cut pass has been completed power off router and clear cutting area of debris.
23.  Move router template to next set of alignment holes and secure in place by means of flathead m3 bolts.
24.  Repeat steps 16-24 until all cutouts

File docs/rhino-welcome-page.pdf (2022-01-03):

Welcome to the Rhino Multi-Tool Manufacturing system, your partner in creativity. Thank you for choosing us!

When we were developing the Rhino we had a couple goals we wanted to target:

Ease of use-We wanted a machine that was not only easy to work with but easy to adjust when maintenance was due. We think this was achieved through our unique belt tensioning system and the standardization of various aspects throughout the machine. Rather than shy away from maintenance, we embrace and realize it is a part of well maintained machine.

Swappable Tools-To achieve the ability for Rhino to have interchangable tools we developed a tool swapping system focused around semi to long-term projects. We recognize that sometimes a user will want to focus on one aspect of the build process to achieve a desired result. Your not going to find super fancy or overly complex toolchanging systems with the Rhino, it’s a click n pop and it’s off.

Enclosed Build Chamber-Safety-wise an enclosed build chamber makes sense, no chance of Fido accidentally plunging his hand into the build area with walls to safely protect things. The natural biproduct of the enclosed build chamber, more consistent ambient temperatures, or with the added chamber heater, elevated build chamber temperatures lends themselves to a higher quality print print.

Expandability-This is an open source project, meaning that if a person wanted to they could develop their own tools for the Rhino. We’ve left the door wide open for development whether it’s through the open design or the open source firmware(Klipper) that is used to control Rhino.

Fun-We said it, and we know it’s corny ....but. It’s a fun system. Use it to create works ranging in such an array of brilliant materials, or do like a lot and tinker away with it.

# Multi-Tool

# Motion System

# Rhino

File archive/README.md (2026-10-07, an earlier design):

# Archive

Old files kept for reference. **Don't use these on a current Rhino** - the current config, macros and portal are in
[Toolhead_Manager](https://github.com/Makersmic/Toolhead_Manager).

| Folder / file | What it is |
|---|---|
| [2023-firmware](2023-firmware/) | Klipper configs and macros from the 2023 build (SKR GTR + M5 board, Jack Rabbit era): per-tool configs, M600, tooling ID, ESC, 4-pin fan and heated-bed notes |
| [2023-apps](2023-apps/) | LaserWeb 4 setup notes |
| [2026-09-ai-spec.md](2026-09-ai-spec.md) | An AI briefing written in Sept 2026. **Outdated:** it numbers tools from slot 0; the current system uses slots 1-5 |

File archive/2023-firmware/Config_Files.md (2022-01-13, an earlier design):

01-12-2022
For now iahve found that i can keep all of the macros for the various printer.cfg files in one file and it not be a problem.  The only conflict arises when i try to envokde a macro that calls upon a function of a different tool.  It may not always throw an error but on some of them it does.

Moving forward i'd like to seperate out the pin configurations into a seperate file.

Currently using Fluidd web interface v0.9.1-609-gf2b4d353 so it's a little dated.  Need to try and migrate over to mainsail since it is supported right now.

Would be nice if someone developed a printer.cfg swapper program.

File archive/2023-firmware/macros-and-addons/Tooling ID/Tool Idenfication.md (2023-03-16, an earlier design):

# Tool Identification
The idea of identifying tools on a multi-tool machine is not a new idea.  It is beneficial to be able to id a tool prior to the machine proceeding with manufacturing for multitude of reasons.
Crashing tools into the build plate or into another spot on the printer can be detremental and potentially damage your machine.  

## Goals
With tool identification i wanted to the following to be accomplished:
-Identify the tool that is currently installed on the machine
-Inform the user of the current tool installed.
-Check if the tool is the correct tool for the job ahead
-Tell the user which should be installed

## How
To identify each tool i am going to be using simple resistors who's values will be different that the printer can read the voltages/resistance of each and make a determination of which tool is installed.  Currently the tools are connected to the control board in a manner that does not conflict with each other or conflict with the printers normal operation, meaning no additional firmware changes are required for the use of each tool.  Users can simply< while the machine is powered down) disconnect the current tool and connect the new tool.

I don't want to over-complicate the build process of this which is why using resistors to accomplish distiguishing between the tools is desirable.  Also, this needs to act like a background process, meaning that the sequence of events that unfold during the tool check procedure needs to feel seemless or rather 'standard', like they were meant to be there the whole time and its not some clumsy add-on.

## The Code
[heater_fan_pin] #use a thermistor pin set,this may cause issue though since i am using a gtr and the m5 daughter board, i haven't figured out yet why i get unstable off the m5 board.
pin: your_pin_number_here

[tool_id]
#Ties the Tool to a certain resistor value
pin: heater_fan_pin
resistor: your_resistor_value_here
tolerance: 5
values:
    100: "Tool 1" #3d printer, 0.4 brass, volcano
    500: "Tool 2" #3d printer, 0.8 brass, volcano
    1000: "Tool 3" #3d printer, 0.4 steel, volcano
    2000: "Tool 4" #3d printer, 0.8 steel, volcano
    3000: "Tool 5" #laser
    5000: "Tool 6" #cnc spindle
    10000: "Tool 7" #drag knife
    20000: "Tool 8" #future
    100000: "Maintenance Tool"

[gcode_macro TOOL_CHECK]
variable_tool_id: {printer.gcode_macro.TOOL_ID()}
variable_tool_name: ""
{% if variable_tool_id is none %}
    ### No tool detected ###
    M117 No tool detected
    M300 S440 P200
    M0
{% else %}
    {% set tool_name = printer.config.gcode_macro.TOOL_ID.values.get(variable_tool_id) %}
    {% if tool_name is none %}
        ### Unknown tool detected ###
        M117 Unknown tool detected
        M300 S440 P200
        M0
    {% else %}
        {% set variable_tool_name = tool_name %}
        {% if printer.gcode_macro.TOOL_ID.expected_id is not none and variable_tool_id != printer.gcode_macro.TOOL_ID.expected_id %}
            ### Wrong tool "{{variable_tool_name}}" detected, expected "{{printer.config.gcode_macro.TOOL_ID.values.get(printer.gcode_macro.TOOL_ID.expected_id)}}"
            M117 Wrong tool "{{variable_tool_name}}" detected, expected "{{printer.config.gcode_macro.TOOL_ID.values.get(printer.gcode_macro.TOOL_ID.expected_id)}}"
            M300 S440 P200
            M0
        {% else %}
            # Tool "{{variable_tool_name}}" detected
            M117 Tool "{{variable_tool_name}}" detected
        {% endif %}
    {% endif %}
{% endif %}

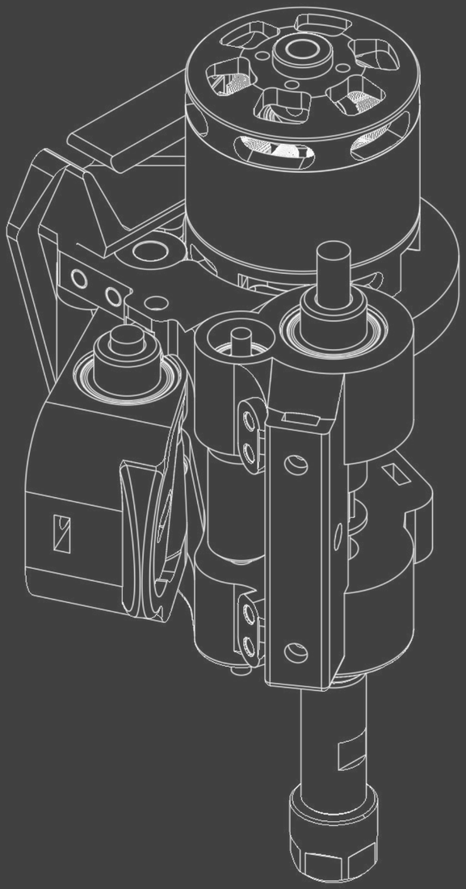
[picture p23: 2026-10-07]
toolheads/hotjoe/images/hotjoe-dark.png

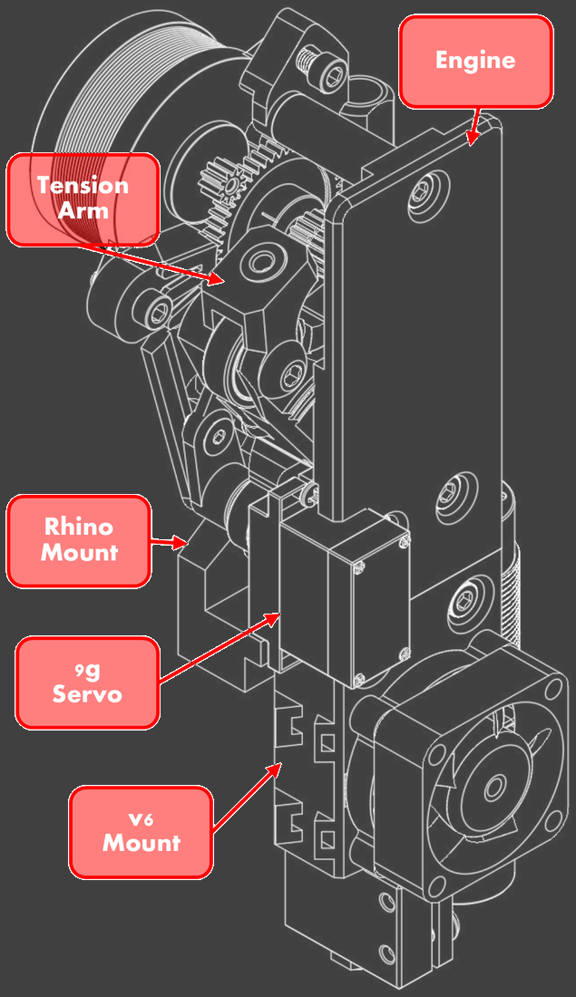
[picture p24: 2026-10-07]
toolheads/switchfly/images/switchfly-dark.png

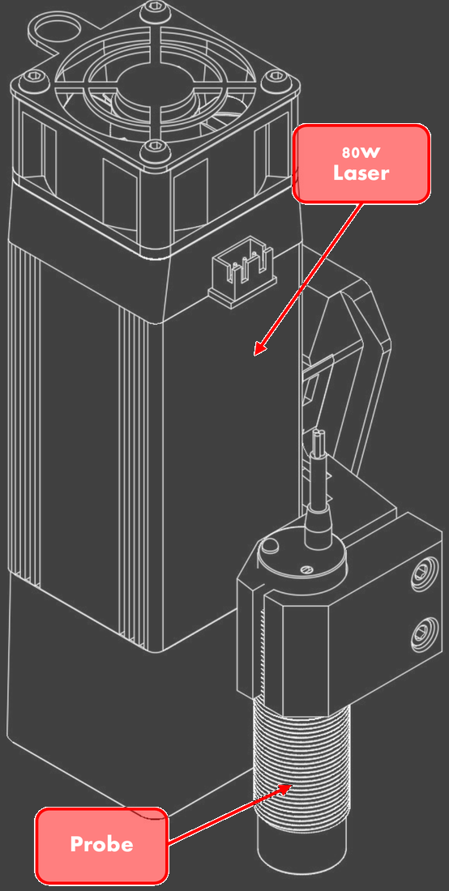
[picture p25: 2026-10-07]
toolheads/lightsaber/images/lightsaber-dark.png

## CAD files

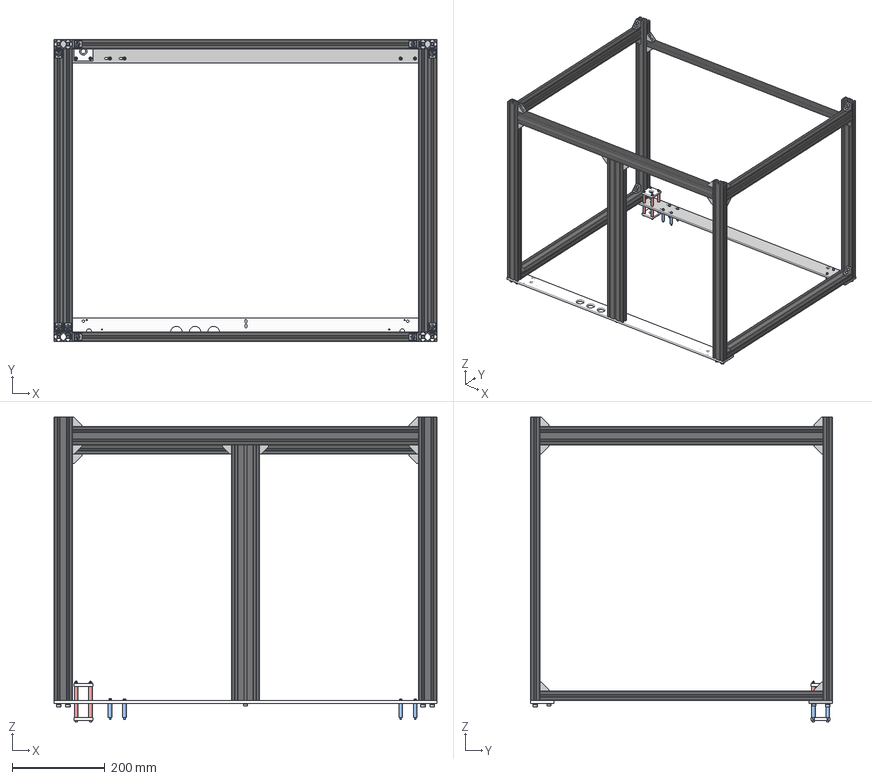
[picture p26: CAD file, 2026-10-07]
frame/Frame Assembly.step
823.9 x 649.6 x 655.9 mm
2040 x 24in x 8
Rear Top Frame Flat Bar
Front Top Frame Flat Bar
2040 x 744mm
5537T228
m6 washer v2 x 8
m6 x 20mm Hex Socket Head x 8
Cast Corner Bracket x 22
M5 x 12mm x 9
90965A160 x 53
2060 x 550mm
m3 x 30mm Spacer x 9
m3 x 30mm Standoff x 8
Motion System Bracket x 2
m5 Hammernut x 44
m5 x 10mm Button Head Hex Drive Bolt x 44
m3 x 12mm Socket Head Screw x 8
m3 Washer x 16
m3 x 85mm Steel Socket Head Screw x 4
m3 Hex Nut x 4

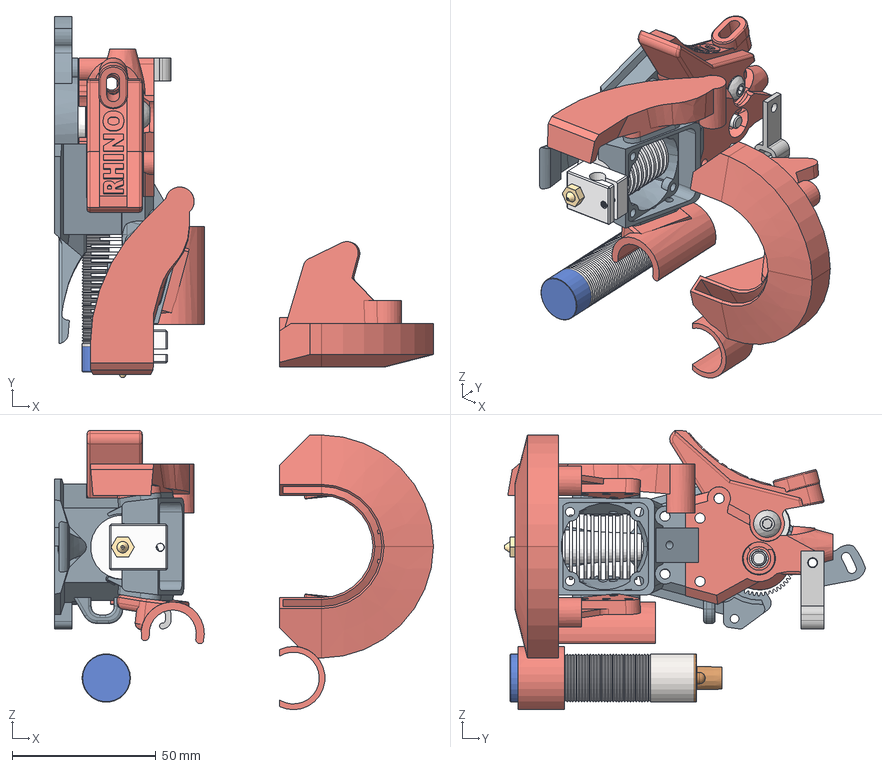
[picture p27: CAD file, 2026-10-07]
toolheads/jack-rabbit/Jack Rabbit Assembly.step
131.7 x 125.5 x 97.1 mm
Jack Rabbit Mount v1
Fan Cowling v1
XY Joiner 1_BMG Volcano Mount-new start_Jack Rabbit Main Body (2) v1
Mellow_BMG_Aero_Gear_shaft v1
Mellow_BMG_Aero_filwheel v9
Spur Gear (50 teeth)
Mellow_BMG_Aero_3mm_set v1
Mellow_BMG_Aero_filwheel2 v3
Heatbreak
Heaterblock
Nozzle 0.4mm
Heatsink
625zz v2
Sensor Body
Frame Assembly-Complete_m5 x 14

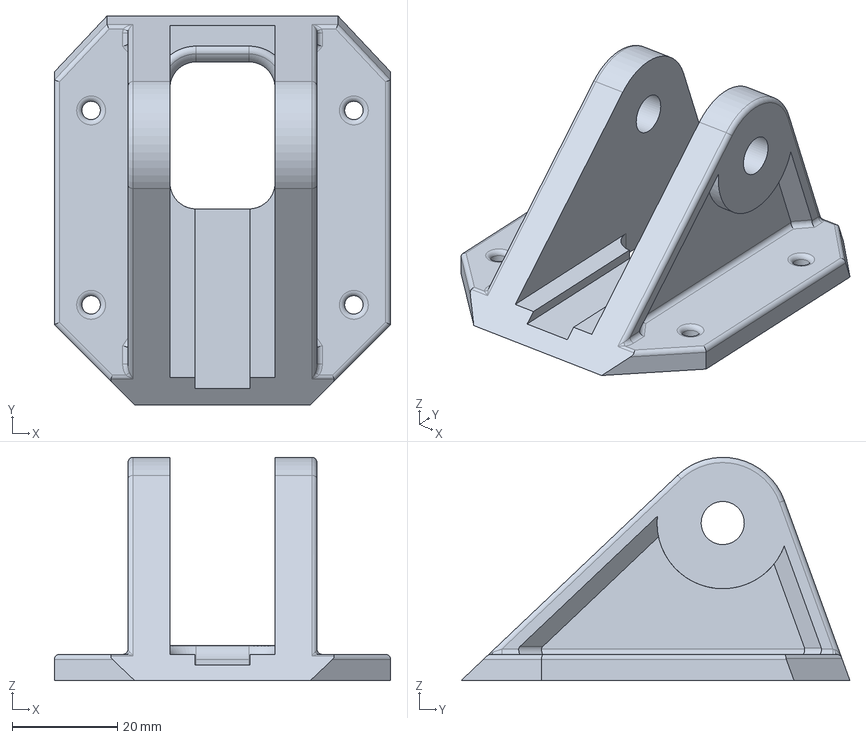
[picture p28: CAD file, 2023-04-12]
motion/xy/x-carriage/Back Bone Mount Main Body.step
64.0 x 74.0 x 42.5 mm

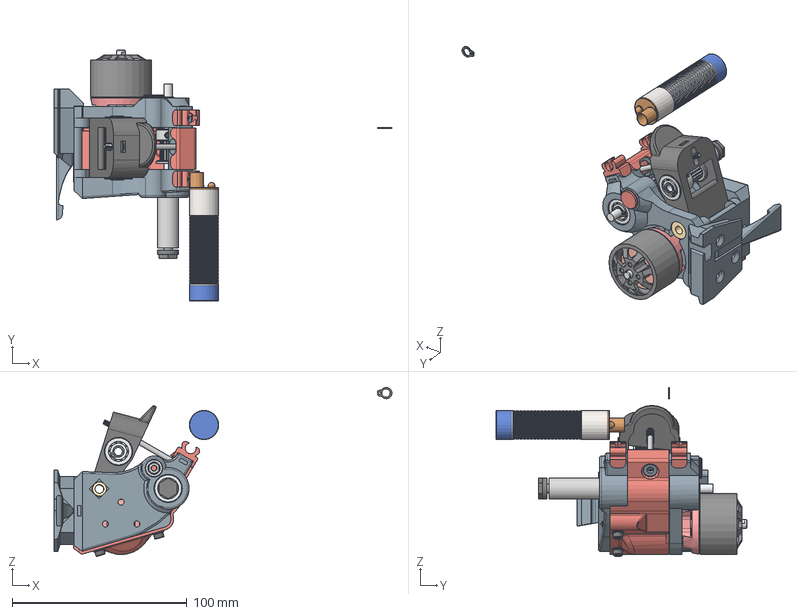
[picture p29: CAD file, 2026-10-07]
toolheads/hotjoe/Spindle Assembly.step
193.2 x 143.5 x 96.7 mm
Tensioner Body
Spindle Guard
Blow Air Clip x 2
6659K66_Oil-Embedded Flanged Sleeve Bearing x 2
Spindle Main Body v4
ER8 Spindle
m3 Washer x 2
625zz x 6
Output Bearing
Shaft 2814
Motor Front 2814
Stator 2814
Inside Bearing
Bell 2814
Tool Mount Blank v1
623Z x 4
Bearing Cap
m3 x 10 x 2
98541A113_External Retaining Ring x 4
16T 10mm GT2 x 3
91290A137_Black-Oxide Alloy Steel Socket Head Screw
m3 Square Nut China
Sensor Body

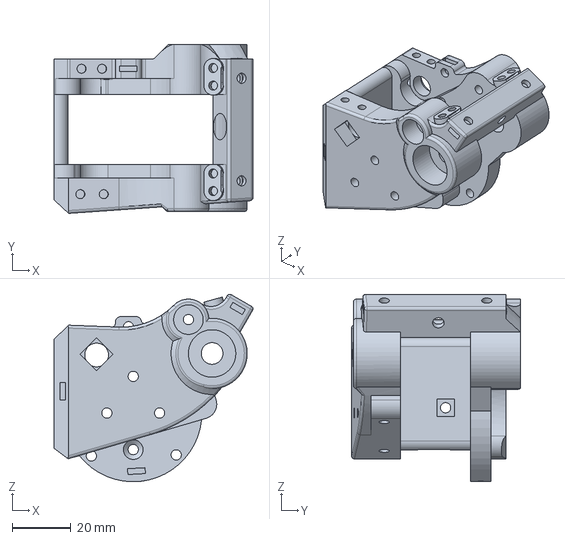
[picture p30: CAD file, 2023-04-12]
toolheads/hotjoe/Spindle Main Body.step
67.9 x 57.6 x 64.0 mm

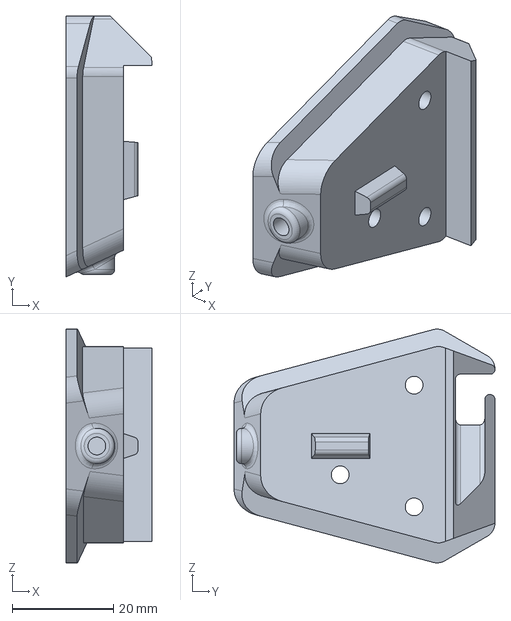
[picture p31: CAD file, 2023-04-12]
toolheads/hotjoe/Main Body Mount Clip v2.step
17.0 x 51.5 x 46.1 mm

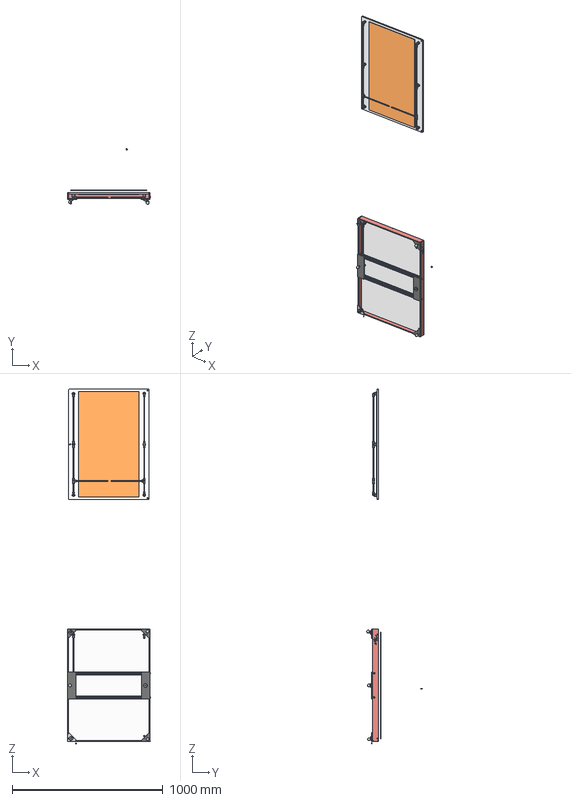
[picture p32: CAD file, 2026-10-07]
bed/Heat Spreader.step
553.2 x 371.0 x 2356.6 mm
190660 QSL-3_8-6 x 6
190670 QST-3_8-6 x 2
ACOPLE T x 2
Pieza2 x 6
Pieza3 x 6
Pieza4 x 6
Pieza5 x 6
Pieza6 x 6
Tube 1 x 2
Tube 2 x 2
Tube 3 x 3
M6
m6 washer x 8
93886A260_Reinforced Plastic Knurled-Head Thumb Nut x 5
m3 Washer x 10
5537T228 x 2
m3 x 10
91290A207_Black-Oxide Alloy Steel Socket Head Screw

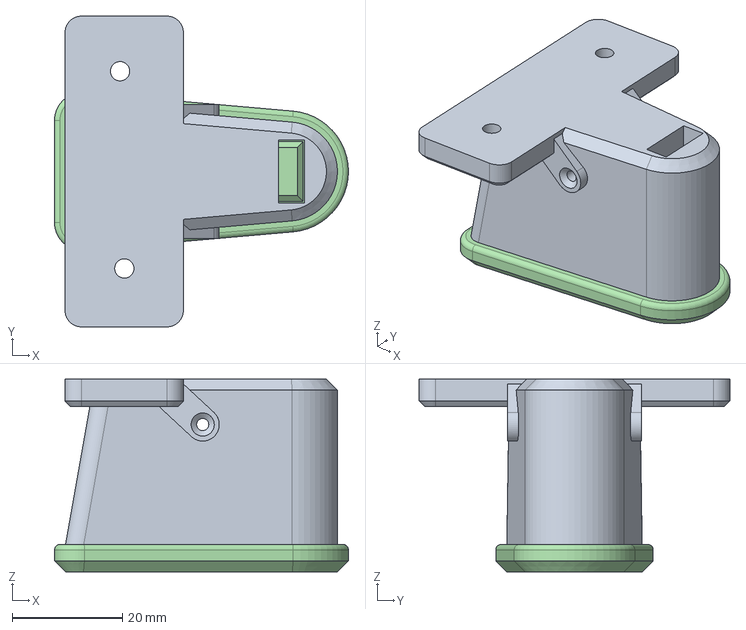
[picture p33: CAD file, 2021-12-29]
filament-box/Filament Runout Swich v5.step
53.4 x 56.4 x 35.0 mm

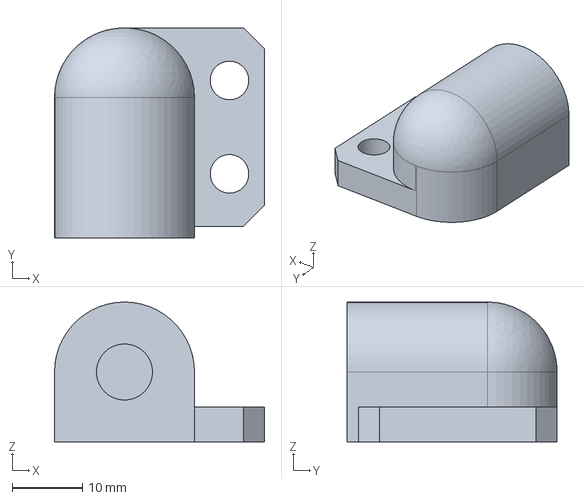
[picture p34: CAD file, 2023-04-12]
frame/panels/door-hardware/Hinge Mirror.step
30.0 x 30.0 x 20.0 mm

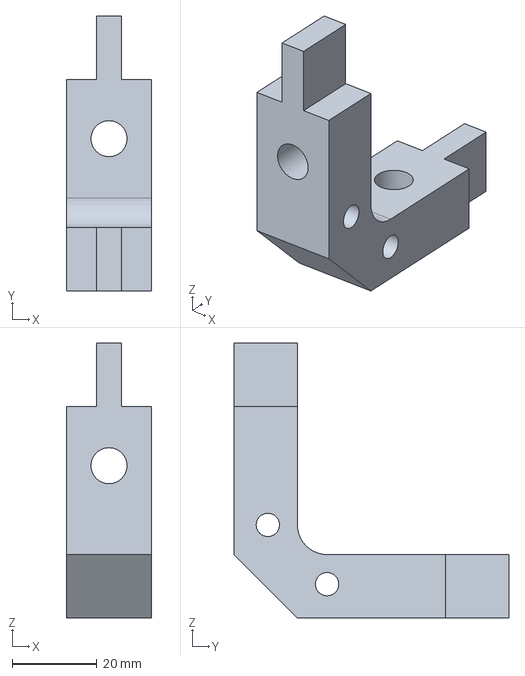
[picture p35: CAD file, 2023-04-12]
frame/panels/front-spacer-assembly/Front Spacer Corner Bracket.step
20.0 x 65.0 x 65.0 mm

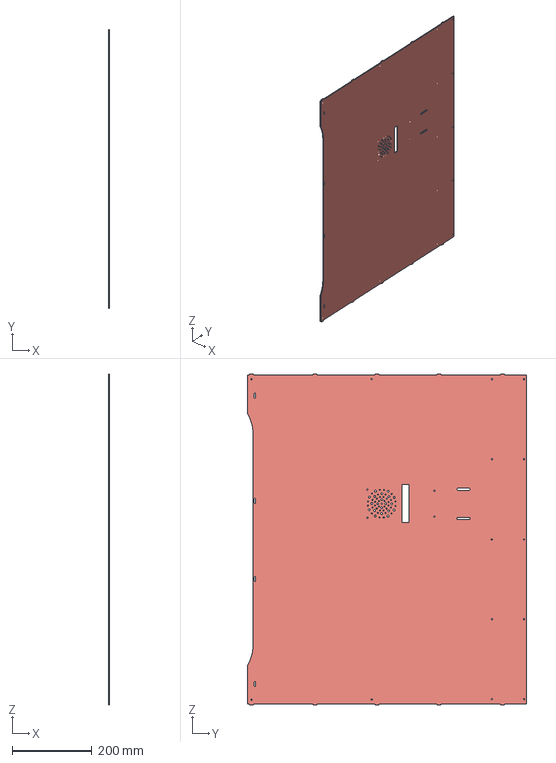
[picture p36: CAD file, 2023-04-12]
frame/panels/Rear Panel-Outer.step
3.00 x 699.6 x 829.9 mm

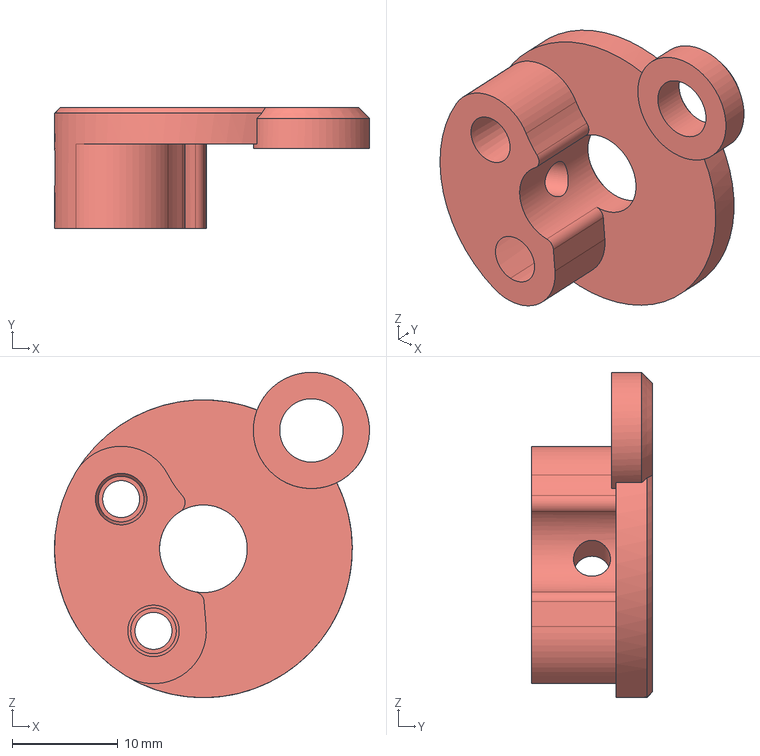
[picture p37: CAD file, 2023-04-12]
motion/xy/belt-tensioner/cam-assembly/Cam PC1.step
29.8 x 11.4 x 30.8 mm

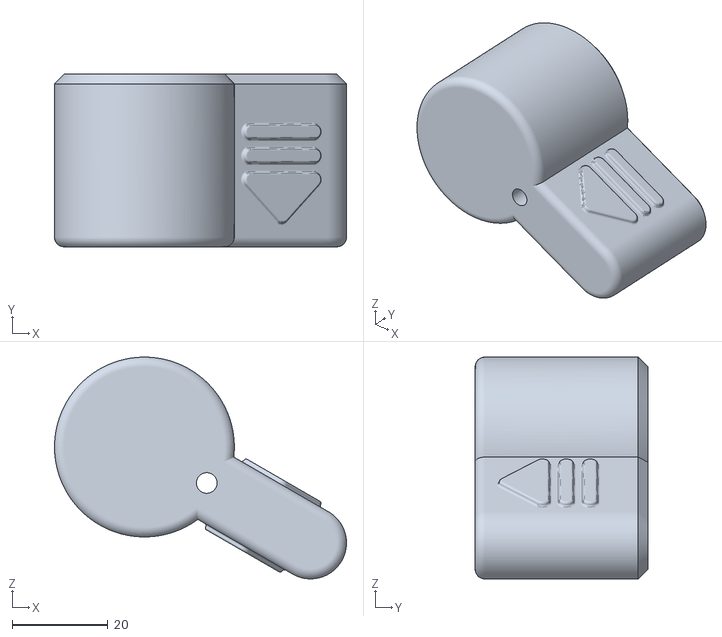
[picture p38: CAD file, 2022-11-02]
motion/xy/belt-tensioner/knob-assembly/Adjustment Knob.stl
60.9 x 36.0 x 46.2

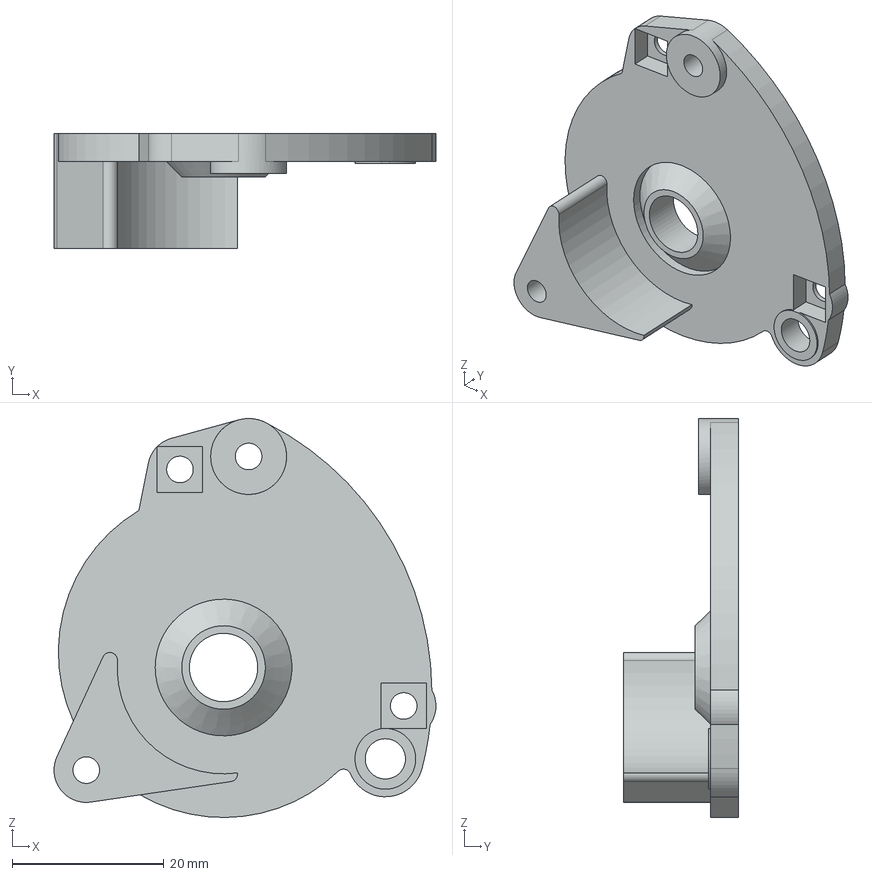
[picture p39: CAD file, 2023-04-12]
motion/xy/belt-tensioner/Tensioner PC3.step
50.3 x 15.1 x 52.5 mm

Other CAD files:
motion/xy/x-carriage/Back Bone Main Body.stl
motion/xy/rear-center-idler/15mm idler bottom.step
motion/xy/stepper-mounts/Torque Buddy v4.step
motion/xy/x-carriage/Bearing Spacer.step
frame/panels/Control Panel-Right.step
frame/panels/Front Inner Panel v4.step
frame/panels/Front Panel-Inner.step
frame/panels/Front Top Inner Panel.step
frame/panels/Rear Inner Top Panel v6.step
frame/panels/Side Panel-Left & Right.step
frame/panels/door-hardware/Hinge Pin.step
frame/panels/door-hardware/Hinge.step
frame/panels/door-hardware/Left Door.step
frame/panels/door-hardware/Right Door.step
frame/panels/front-spacer-assembly/Front Upper Spacer.step
frame/panels/front-spacer-assembly/Front Lower Spacer-Left.step
frame/panels/front-spacer-assembly/Front Lower Spacer-Right.step
frame/panels/front-spacer-assembly/Front Spacer Lower-Side.step
frame/panels/front-spacer-assembly/Front Top Spacer Left.step
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

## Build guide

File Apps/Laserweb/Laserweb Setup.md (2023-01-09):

The following settings and gcode are geared towards Laserweb 4.0.  While the following may work for previous versions or in fact other software, it has not been tested otherwise.  

To setup Laserweb perform the following:
1.  Click on Settings
2.  Click on Gcode
3.  Ensure the following is in the "Gcode Start" section:
      home        ; Rhino default homing sequence
      G1 F1000    ; Set the feedrate
      G21         ; Set units to mm
      G90         ; Absolute positioning
      M106 S230   ; Set the part cooling fan to 75%
      SET_PIN PIN=VACPUMP_pin VALUE=1   ;Power on the laser module
      
4.  Ensure the following is in the "Gcode End" section:
      G1 Z220 F1000     ;Lower the build plate
      M106 S0           ;Turn off the part cooling fan
      SET_PIN PIN=VACPUMP_pin VALUE=0   ;Power off the laser module
      
5.  Ensure the following is in the "Tool Off Section":
      SET_PIN PIN=LASERPOWER_pin VALUE=0  ;Set the laser pwm signal to '0'.

6.  Ensure the following is in the "Laser Intensity" section;
      SET_PIN PIN=LASERPOWER_pin VALUE=
      
7.  Ensure that '0' is in the "PWM MIN S VALUE" field.

8.  Ensure that '1' is in the "PWM MAX S VALUE" field.

9.  "Gcode Homing" and "Tool On" sections are to be left blank intentionally.

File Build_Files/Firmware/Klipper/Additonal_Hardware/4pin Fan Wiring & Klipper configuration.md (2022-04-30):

As there are a few examples floating around the internet i found this guide helpful in configuring the 4 pin fan used for the part cooling solution of the Rhino.

The tutorial below illustrates an example for a 4 pin fan, but this same method may be used for 5 pin fans.  This is especially useful for driving delta fans, ensure
your mosfet is rated for the current draw of the delta fan.  Delta fans typically draw more amperage than normal case fans.  Check your fan for appropriate pinout information prior!

https://www.nicksherlock.com/2022/01/driving-a-4-pin-computer-pwm-fan-on-the-btt-octopus-using-klipper/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

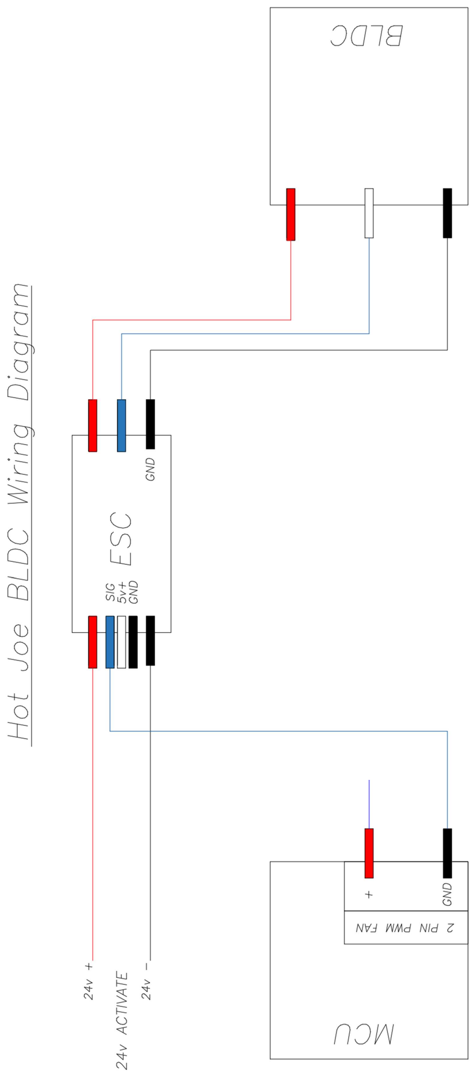
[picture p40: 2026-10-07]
electrical/images/wiring-hotjoe-esc.png

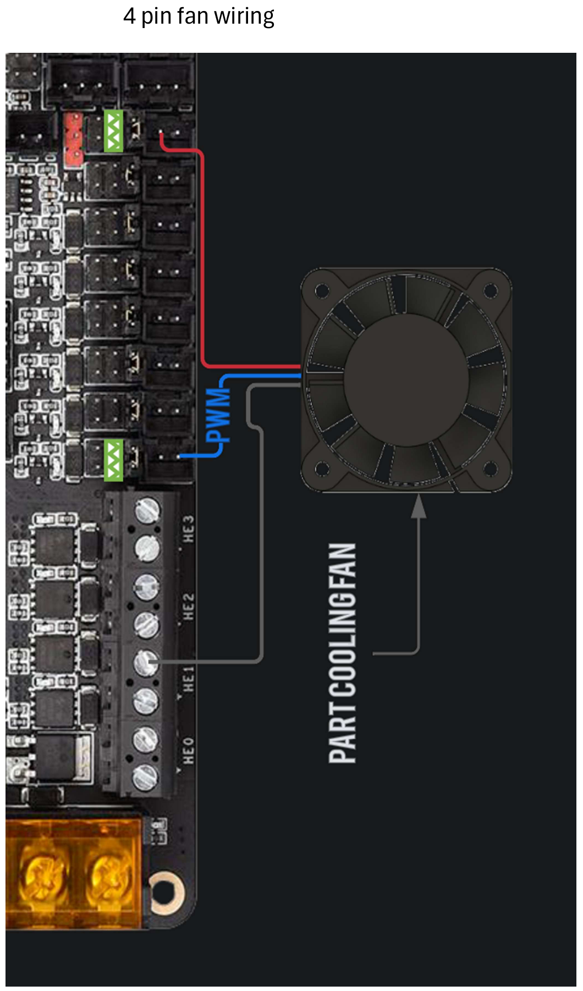
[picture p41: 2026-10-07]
electrical/images/wiring-4pin-fan.png

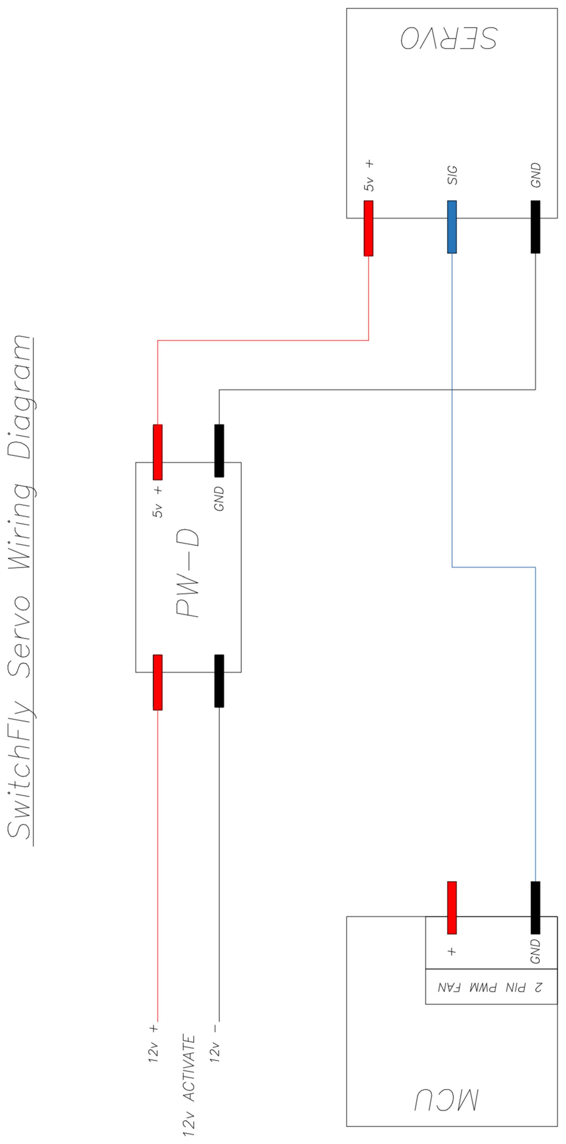
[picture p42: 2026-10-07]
electrical/images/wiring-switchfly-servo.png

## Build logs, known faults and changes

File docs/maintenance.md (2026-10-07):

# Maintenance

> **Maintenance tracking now exists.** The [Tool Manager](https://github.com/Makersmic/Toolhead_Manager) portal tracks tasks by production hours, jobs, tool
> swaps or calendar time - for the machine and for every toolhead - with a work log and dashboard. The list below was
> the original plan and is covered by its Task Library.

## Scheduled maintenance items
- Belt stretch
- Bearings
- Leadscrew cleaning and lubricating
- General cleaning of the underside

## Service bay (idea)
When i think about  a maintenance bay, a user may put a tool into said bay and the user be able to service a tool.  Functions that
a service bay would need to be facilitate all of the tools by default.  The bay would need meet all of the requirements that umbilical holds while also having the ability to test 
components such as endstops or other possible hardware.

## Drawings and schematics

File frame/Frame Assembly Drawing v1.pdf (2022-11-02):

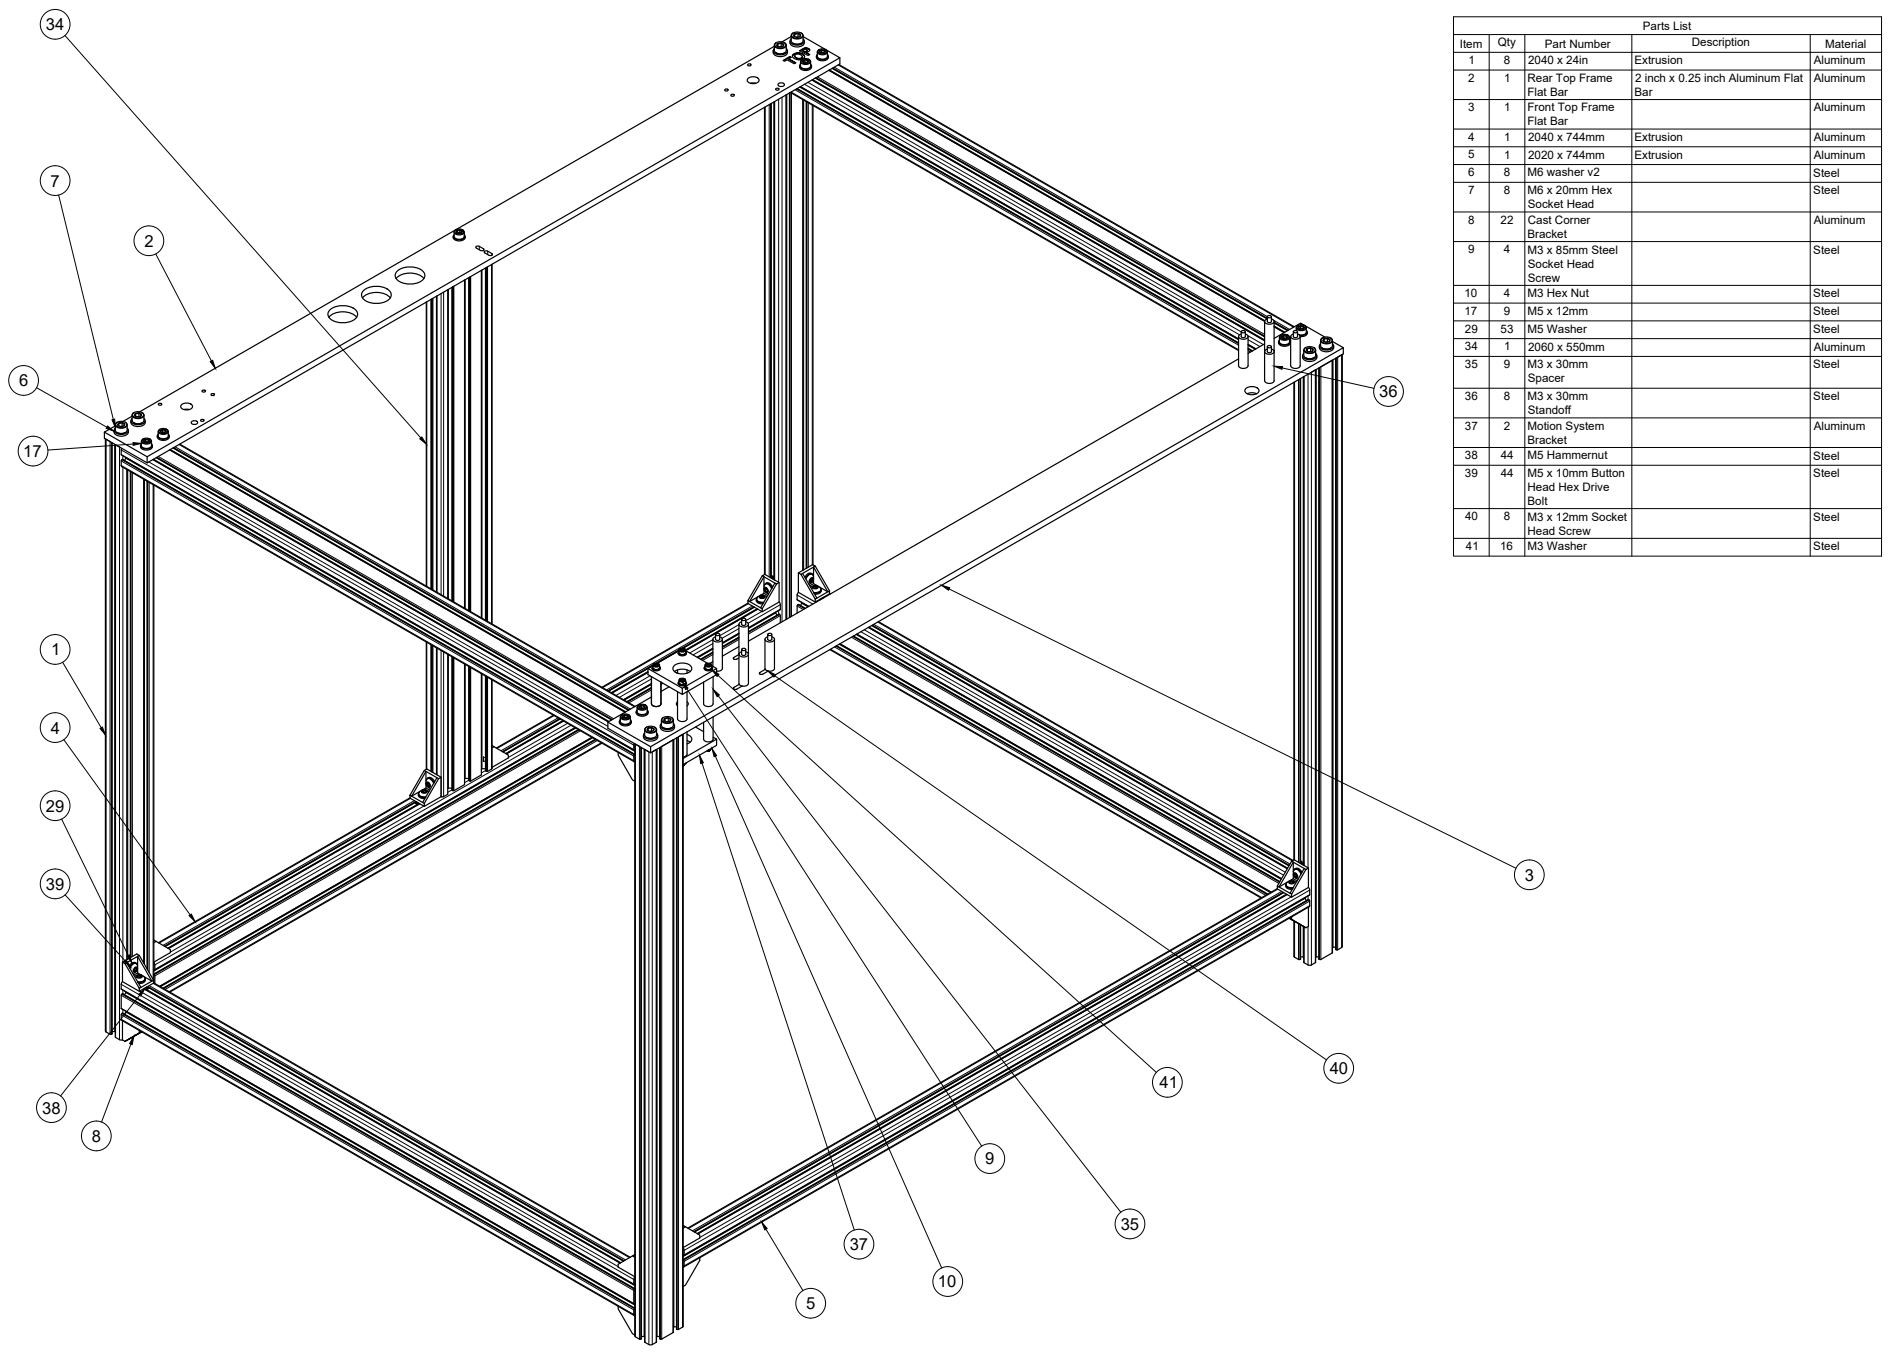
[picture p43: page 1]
Parts List; M3 Washer; Steel 5 8

Item | Qty 8 1 | Rear Top Frame 2040 x 24in Part Number | Extrusion Description | Aluminum 2 Material 1

1 | Front Top Frame Flat Bar | 2 inch x 0.25 inch Aluminum Flat Bar | Aluminum 3

8 8 1 1 | M6 washer v2 M6 x 20mm Hex 2040 x 744mm 2020 x 744mm | Extrusion | Steel 7 Aluminum 4 Aluminum 5 Aluminum 6

Flat Bar

22 | Cast Corner Socket Head | | Steel 8

4 | M3 x 85mm Steel Bracket | | Aluminum 9

Socket Head Screw | | Steel

10 | 4 | M3 Hex Nut | | Steel
17 | 9 | M5 x 12mm | | Steel
29 | 53 | M5 Washer | | Steel
34 | 1 | 2060 x 550mm | | Aluminum
35 | 9 | M3 x 30mm Spacer | | Steel

36 | 8 | M3 x 30mm Standoff | | Steel

37 | 2 | Motion System Bracket | | Aluminum

38 | 44 | M5 Hammernut | | Steel
39 | 44 | M5 x 10mm Button Head Hex Drive Bolt | | Steel

40 | 8 | M3 x 12mm Socket Head Screw | | Steel

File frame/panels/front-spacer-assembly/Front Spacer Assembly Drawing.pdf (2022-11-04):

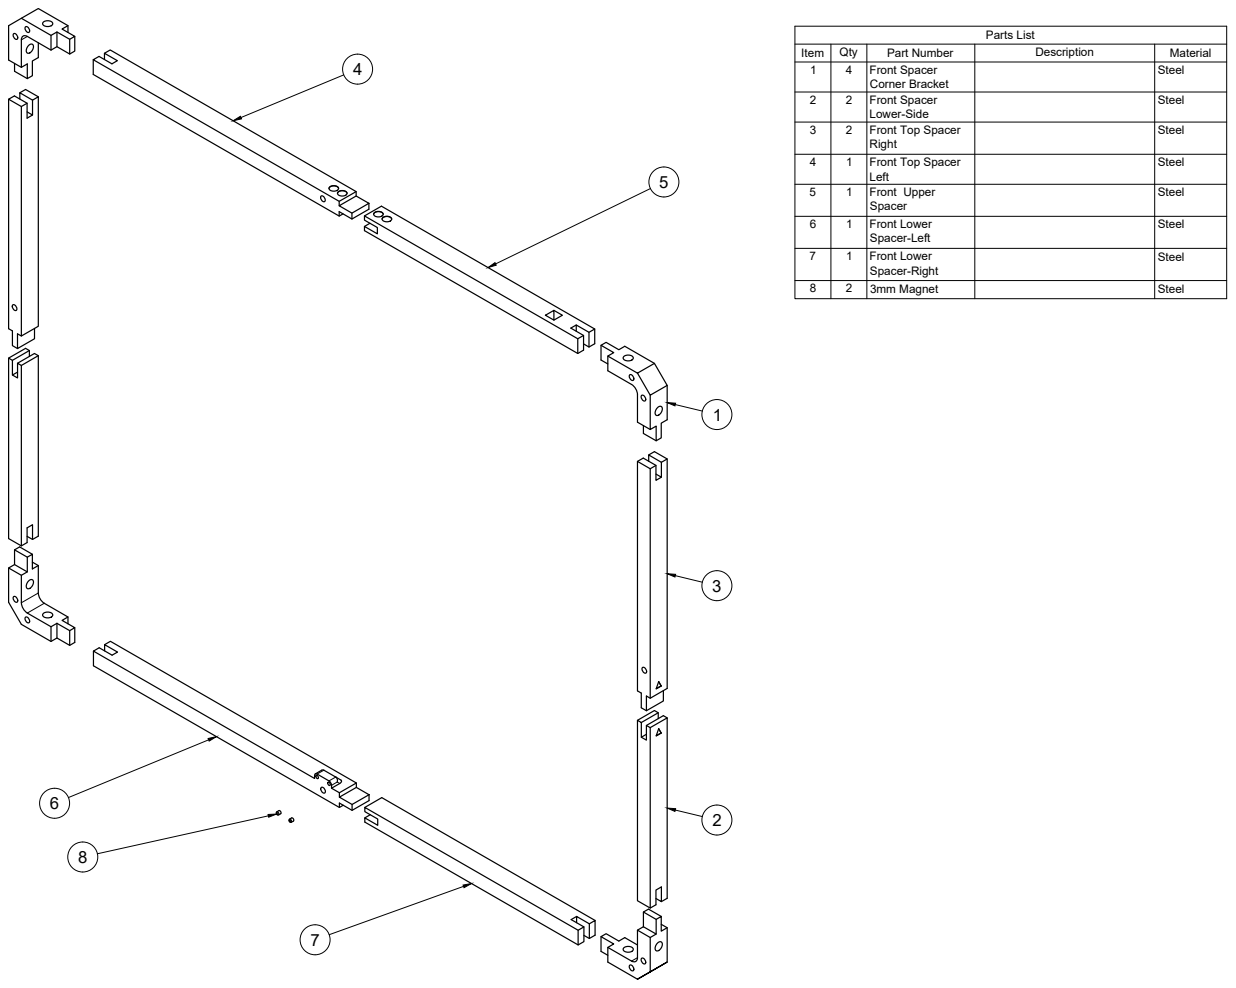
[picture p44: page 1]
Parts List

Item | Qty | Part Number | Description | Material
1 | 4 | Front Spacer Corner Bracket | | Steel

2 | 2 | Front Spacer Lower-Side | | Steel

3 | 2 | Front Top Spacer Right | | Steel

4 | 1 | Front Top Spacer Left | | Steel

5 | 1 | Front Upper Spacer | | Steel

6 | 1 | Front Lower Spacer-Left | | Steel

7 | 1 | Front Lower Spacer-Right | | Steel

8 | 2 | 3mm Magnet | | Steel

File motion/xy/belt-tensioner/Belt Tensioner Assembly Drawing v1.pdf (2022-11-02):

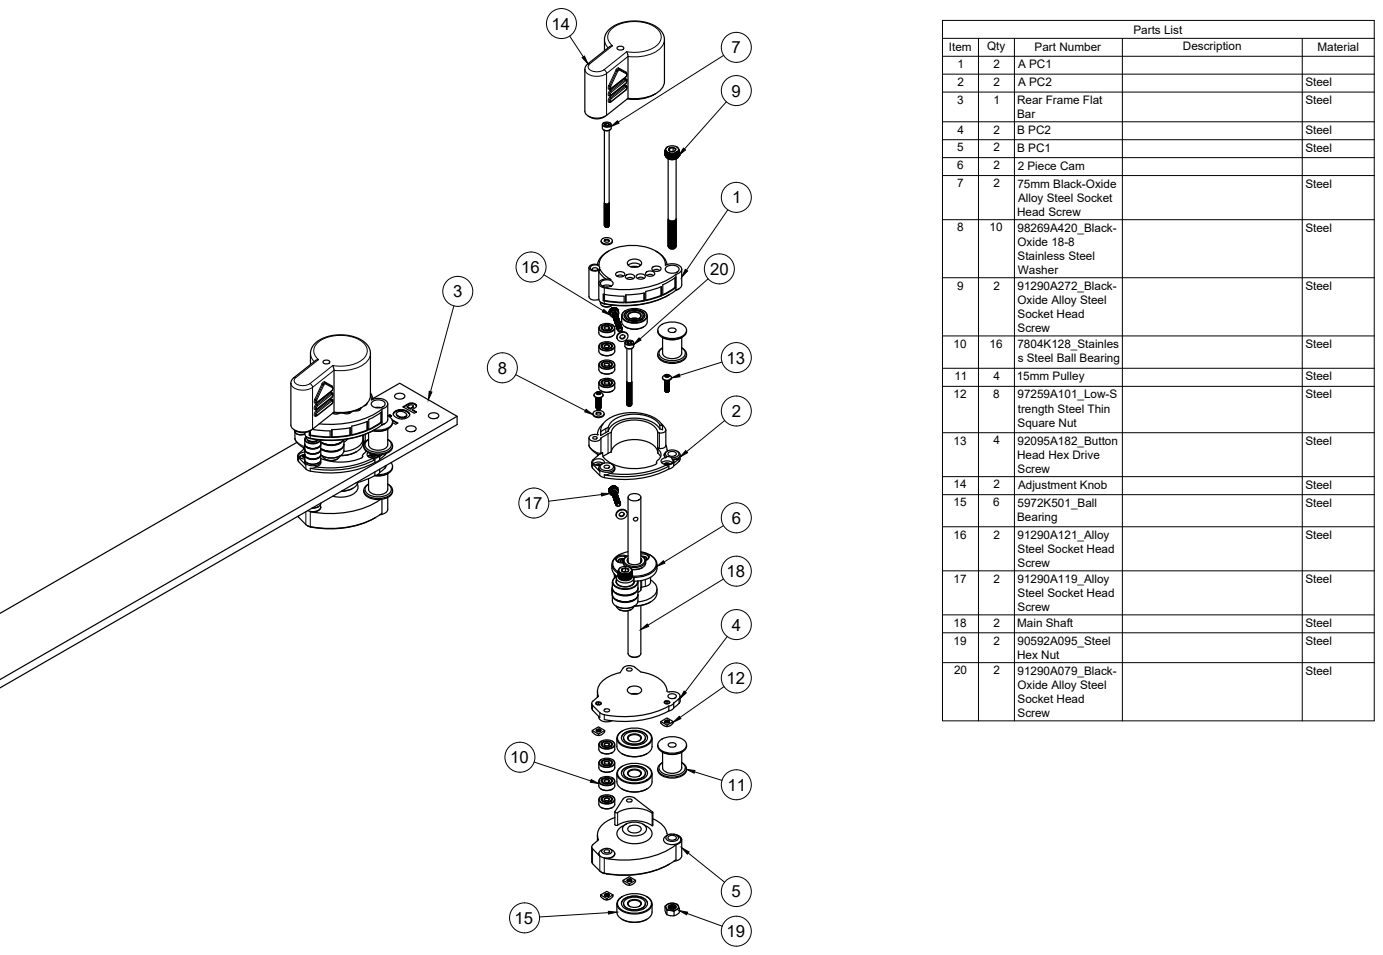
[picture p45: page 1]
Parts List

Item | Qty 2 2 1 | Rear Frame Flat A PC1 2 A PC2 Part Number | Description | Steel 3 Material 1

2 2 | B PC2 B PC1 75mm Black-Oxide 2 Piece Cam 7 | | Steel 4 Steel 5 Steel 6

Bar

10 | 98269A420_Black-Alloy Steel Socket Head Screw | | Steel 8

2 | 91290A272_Black-Oxide 18-8 Stainless Steel Washer | | Steel 9

Oxide Alloy Steel Socket Head Screw | | Steel

10 | 16 | 7804K128_Stainles s Steel Ball Bearing | | Steel

11 | 4 | 15mm Pulley | | Steel
12 | 8 | 97259A101_Low-S trength Steel Thin Square Nut | | Steel

13 | 4 | 92095A182_Button Head Hex Drive Screw | | Steel

14 | 2 | Adjustment Knob | | Steel
15 | 6 | 5972K501_Ball Bearing | | Steel

16 | 2 | 91290A121_Alloy Steel Socket Head Screw | | Steel

17 | 2 | 91290A119_Alloy Steel Socket Head Screw | | Steel

18 | 2 | Main Shaft | | Steel
19 | 2 | 90592A095_Steel Hex Nut | | Steel

20 | 2 | 91290A079_Black-Oxide Alloy Steel Socket Head Screw | | Steel

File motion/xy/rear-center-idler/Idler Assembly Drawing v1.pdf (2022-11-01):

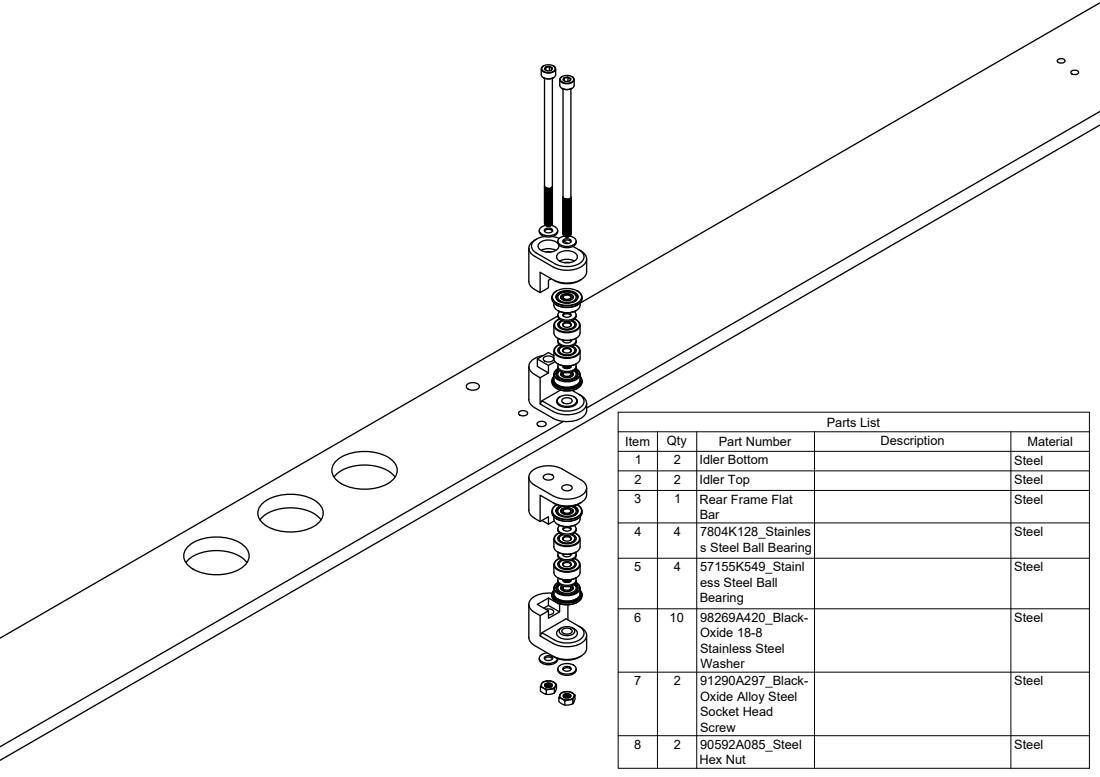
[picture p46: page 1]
Parts List

Item | Qty | Part Number | Description | Material
1 | 2 | Idler Bottom | | Steel
2 | 2 | Idler Top | | Steel
3 | 1 | Rear Frame Flat Bar | | Steel

4 | 4 | 7804K128_Stainles s Steel Ball Bearing | | Steel

5 | 4 | 57155K549_Stainl ess Steel Ball Bearing | | Steel

6 | 10 | 98269A420_Black-Oxide 18-8 Stainless Steel Washer | | Steel

7 | 2 | 91290A297_Black-Oxide Alloy Steel Socket Head Screw | | Steel

8 | 2 | 90592A085_Steel Hex Nut | | Steel

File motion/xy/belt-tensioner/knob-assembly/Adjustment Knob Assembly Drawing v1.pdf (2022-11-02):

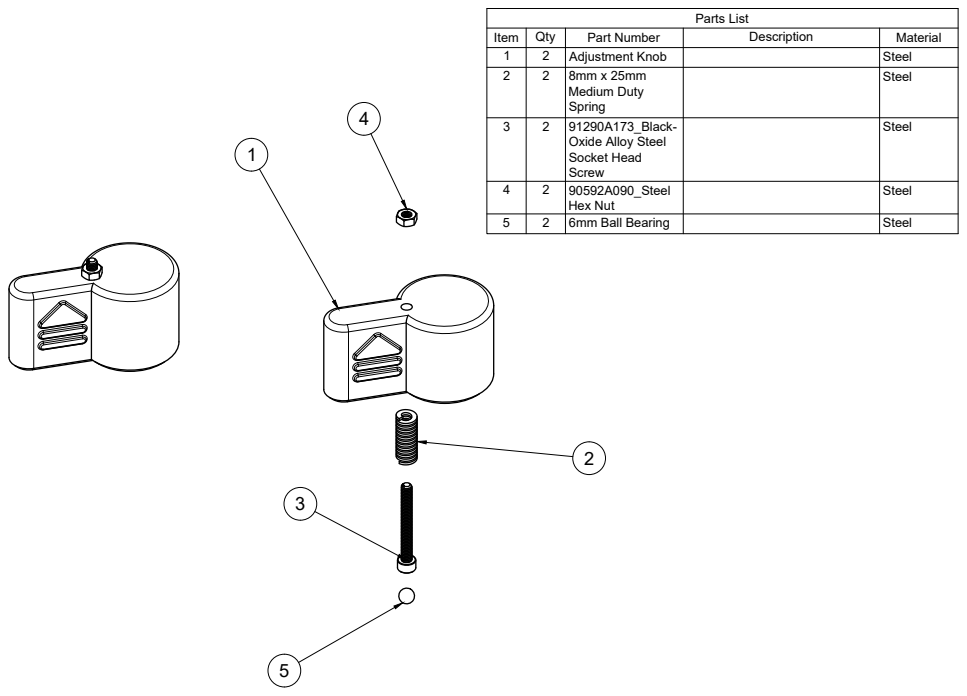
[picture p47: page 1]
Parts List

Item | Qty | Part Number | Description | Material
1 | 2 | Adjustment Knob | | Steel
2 | 2 | 8mm x 25mm Medium Duty Spring | | Steel

3 | 2 | 91290A173_Black-Oxide Alloy Steel Socket Head Screw | | Steel

4 | 2 | 90592A090_Steel Hex Nut | | Steel

5 | 2 | 6mm Ball Bearing | | Steel

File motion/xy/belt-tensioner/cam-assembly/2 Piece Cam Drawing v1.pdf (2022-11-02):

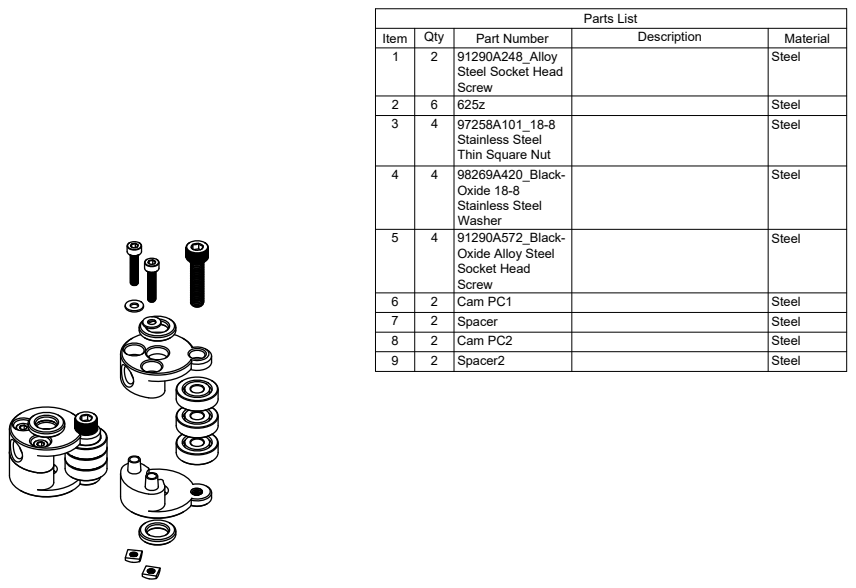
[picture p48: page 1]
Parts List

Item | Qty | Part Number | Description | Material
1 | 2 | 91290A248_Alloy Steel Socket Head Screw | | Steel

2 | 6 | 625z | | Steel
3 | 4 | 97258A101_18-8 Stainless Steel Thin Square Nut | | Steel

4 | 4 | 98269A420_Black-Oxide 18-8 Stainless Steel Washer | | Steel

5 | 4 | 91290A572_Black-Oxide Alloy Steel Socket Head Screw | | Steel

6 | 2 | Cam PC1 | | Steel
7 | 2 | Spacer | | Steel
8 | 2 | Cam PC2 | | Steel
9 | 2 | Spacer2 | | Steel

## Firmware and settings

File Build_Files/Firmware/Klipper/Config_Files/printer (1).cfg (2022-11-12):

# This file contains common pin mappings for the BigTreeTech GTR.
# To use this config, the firmware should be compiled for the
# STM32F407 with a "32KiB bootloader".

# The "make flash" command does not work on the GTR. Instead,
# after running "make", copy the generated "klipper/out/klipper.bin" file to a
# file named "firmware.bin" on an SD card and then restart the GTR
# with that SD card.

# See docs/Config_Reference.md for a description of parameters.

#[include printer_menu.cfg]

[include LED/LED.cfg]
[include tools/spindle.cfg]
[include tools/laser.cfg]
[include tools/3dp.cfg]
[include client_macros.cfg]
#[include led.cfg]
[display_status]
[virtual_sdcard]
path: ~/gcode_files

[input_shaper]
[input_shaper]
shaper_freq_x: 32  # frequency for the X mark of the test model
shaper_freq_y: 36# frequency for the Y mark of the test model
shaper_type: mzv

[stepper_x]
step_pin: PC15
dir_pin: !PF0
enable_pin: !PF1
microsteps: 16
rotation_distance: 40
full_steps_per_rotation: 400
endstop_pin: ^PG14
position_endstop: 575
position_max: 575
homing_speed: 50

[stepper_y]
step_pin: PE3
dir_pin: PE2
enable_pin: !PE4
microsteps: 16
rotation_distance: 40
full_steps_per_rotation: 400
endstop_pin: ^PG9
position_endstop: 0
position_max: 406
homing_speed: 50

[stepper_z]
step_pin: PB8
dir_pin: PB7
enable_pin: !PB9
microsteps: 16
rotation_distance: 2
full_steps_per_rotation: 200
gear_ratio: 2:1
#endstop_pin: ^PE0    #now used for probe connection
#position_endstop: 0
position_max: 400
homing_speed: 12
second_homing_speed: 3
endstop_pin: probe:z_virtual_endstop
position_min: -10 # The Z carriage may need to travel below the Z=0
                 # homing point if the bed has a significant tilt.

#on E1
[stepper_z1]
step_pin: PD6
dir_pin: PD5
enable_pin: !PD7
microsteps:16
rotation_distance: 2
full_steps_per_rotation: 200
gear_ratio: 2:1
#heater_pin: PA1 # Heat1
#sensor_pin: PC2 # T1
#...

#on E2
[stepper_z2]
step_pin: PD1
dir_pin: PD0
enable_pin: !PD2
microsteps:16
rotation_distance: 2
full_steps_per_rotation: 200
gear_ratio: 2:1
#heater_pin: PB0 # Heat2
#sensor_pin: PC3 # T2
#...

[output_pin VACPUMP_pin]
# Front Light
pin: PI5 #PB0 #aux:PE4
#pwm: True
value: 0
#cycle_time: 0.010

[output_pin LED_pin]
# Front Light
pin: PE9
pwm: True
value: 0
cycle_time: 0.010

[output_pin Umbilical_LED]
# Front Light
pin: PD15  #aux:PH3
pwm: True
value: 0
cycle_time: 0.010

[output_pin Control_Panel_Fan_Power]
pin: PE5

#[fan]
#pin: PE9 # !aux:PH5 
#hardware_pwm: True
#cycle_time: 0.0003333

[temperature_sensor mcu_temp]
sensor_type: temperature_mcu

[temperature_sensor Chamber_Temp]
sensor_type: Generic 3950
sensor_pin: PA3
min_temp: 0
max_temp: 130

[mcu]
restart_method: command
#restart_method: arduino
serial: /dev/serial/by-id/usb-Klipper_stm32f407xx_16002A001647393335353436-if00

[printer]
kinematics: corexy
max_velocity: 700 #1000    #700
max_accel: 6000 #20000#6000  
max_z_velocity: 8  #8
max_z_accel: 10 #12

########################################
# TMC2208 configuration
########################################

[tmc2209 stepper_x]
uart_pin: PC14
run_current: 1.300
hold_current: 0.500
stealthchop_threshold: 99999

[tmc2209 stepper_y]
uart_pin: PE1
run_current: 1.300
hold_current: 0.500
stealthchop_threshold: 99999

[tmc2208 stepper_z]
uart_pin: PB5
run_current: 0.800
hold_current: 0.500
stealthchop_threshold: 0

[tmc2208 stepper_z1]
uart_pin: PD4
run_current: 0.800
hold_current: 0.500
stealthchop_threshold: 0

[tmc2208 stepper_z2]
uart_pin: PC12
run_current: 0.800
hold_current: 0.500
stealthchop_threshold: 0

########################################
# EXP1 / EXP2 (display) pins
########################################

# display section not tested - pinout should be correct but my LCD did not work yet

[board_pins]
aliases:
    # EXP1 header
    EXP1_1=PC11, EXP1_3=PC10, EXP1_5=PG8, EXP1_7=PG6, EXP1_9=<GND>,
    EXP1_2=PA15, EXP1_4=PA8, EXP1_6=PG7, EXP1_8=PG5, EXP1_10=<5V>,
    # EXP2 header
    EXP2_1=PB14, EXP2_3=PD10, EXP2_5=PH10, EXP2_7=PB10,  EXP2_9=<GND>,
    EXP2_2=PB13, EXP2_4=PB12, EXP2_6=PB15, EXP2_8=<RST>, EXP2_10=<NC>

[display]
lcd_type: hd44780
rs_pin: EXP1_4
e_pin: EXP1_3
d4_pin: EXP1_5
d5_pin: EXP1_6
d6_pin: EXP1_7
d7_pin: EXP1_8
encoder_pins: ^EXP2_3, ^EXP2_5
click_pin: ^!EXP1_2
#kill_pin: ^!EXP2_8

#[output_pin beeper]
#pin: EXP1_1

# Define a probe
[probe]
pin: ^!PI4
x_offset: 20.00
y_offset: 5.00
#z_offset: -0.350
sample_retract_dist: 10 
#samples_tolerance: 0.010

# The safe_z_home section modifies the default G28 behavior
[safe_z_home]
home_xy_position: 287.5,203
speed: 25
z_hop: 10
z_hop_speed: 5.0

[z_tilt]
z_positions: 
    -17.454,-100.383    #front left
    357.4595,515.09     #rear center
    722.454,-100.383     #front right

points:
	50,50    
	287.5,320  #287.5
    450,50  #540
speed: 100
horizontal_move_z: 20
retries: 5
retry_tolerance: 0.05

# Example bed_mesh config section
#[bed_mesh]
#mesh_min: 40,40
#mesh_max: 500,300
#probe_count: 5,3

#*# <---------------------- SAVE_CONFIG ---------------------->
#*# DO NOT EDIT THIS BLOCK OR BELOW. The contents are auto-generated.
#*#
#*# [probe]
#*# z_offset = 0.480
#*#

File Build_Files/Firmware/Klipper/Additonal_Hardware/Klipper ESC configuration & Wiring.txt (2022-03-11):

To begin, ensure you have a working Klipper printer.cfg file configured for your printer as this process will rely upon Klippers ability to us macros.  For this tutorial we will be utilizing the following parts:
-HobbyWing 80a esc
-12v 30a Mechanical Relay
-2 pwm fan port from your control board

Providing Power to the ESC
When using the spindle attachment or any other Rhino attachment that requires the use of an esc it is best thought to only power the esc when said attachments are in use.  We will be providing power through the use of a mechanical relay and connections to the existing power supply that is dedicated for expansion tools.  See wiring diagram below for connecting the power supply, relay, and esc.

ESC Power Cycle Configuration
The Rhino borrows technology from many different communities, if you haven’t figured it out yet the esc we will be using is commonly used in radio control hobbiest community.  There are a couple of sequences that we need to mimic using our 3d printer hardware in order for all the goodies to communicate with each other, but first we need power!  Also note, I did not want to utilize physical hardware buttons but rather have everything controllable through a web interface like Fluidd or Mainsail so macros are a must here.

Macros: ESC_Activate & ESC_Deactivate
The ESC_Activate and ESC_Deactivate macros do not control the pwm speed signal for the esc but rather provide a means of controlling power provided to the esc.  We need a means of turning on and off the power to the esc attachment and these macros can be thought of as the on/off switch for this portion of the Rhino.  

First let’s tell Klipper which pin to use as our on/off switch.  In your printer.cfg file add the following line.

[output_pin ESC_Power]
Pin: aux:PE5
ESC_Activate
Place macro here

ESC_Deactivate
Place macro here

*Note: These macros have been tailored to be compatible with an MKS Rumba+ control board.  Be sure to tailor the pin assignments to suit your needs.

ESC PWM Frequency
To start let’s create a section in printer.cfg file for the esc and choose a set of free pwm pins on the controller board.  Begin by adding the following text:
[output_pin Spindle_pin]
Normally when a 3d printer control board sends a pwm signal it is sent through the positive terminal or lead to the device, we see this all the time with fans that have variable on our printers.  In this case though the esc is looking for a signal coming off of the negative pin from the controller.  To achieve this we have to change the pin state in Klipper, this is achieved through adding an exclamation point at the start of the statement.  Let’s add the following text to our newly created esc section in the printer.cfg file.
[output_pin Spindle_pin]
pin: !rollstand:PE4

As mentioned before we are using a piece of tech from another community and as a result things are not matching, mainly the pwm frequency.  The pwm frequency used on our 3d printer control board is 500Hz while the pwm frequency of the esc is 50Hz.  With these being different we need to tell Klipper to send a pwm signal to the esc using 50Hz.  In this section the frequency is referred to as cycle_time, and we need to tell Klipper the appropriate cycle time for the esc.  I could not get an accurate figure to place in here when I tried using various formulas so I ended up doing what a lot us do and just play.  I played with the sliders in the web interface, I altered the figure used for cycle time and what I landed on was 0.0025.  Adding this will look like
[output_pin Spindle_pin]
pin: !rollstand:PE4
cycle_time: 0.0025

With the cycle time at 0.0025 my minimum throttle position value is 0.3 and the maximum throttle position is 0.99.  Playing with the cycle time value will move the throttle range between 0-1.

Other behaviors we need to mimic for the esc is a pwm signal letting the esc know there is a transmitter/receiver connected when power is provided to the esc.  We do this by providing a pwm signal to the signal pin of the esc when the esc is powered up.  This is achieved through setting the pin value of the pwm pin to the lowest throttle position, in our case it is set to 0.30.  
[output_pin Spindle_pin]
pin: !rollstand:PE4
cycle_time: 0.0025
value: 0.3

Another behavior we need to mimic is training the esc to highest and lowest positions of throttle stick that is normally found on the rc handheld transmitter, this is called calibrating the esc.
---need to add how to calibrate the esc---

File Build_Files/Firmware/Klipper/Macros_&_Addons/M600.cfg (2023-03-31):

[gcode_macro BACK]
gcode:
     M876 S1 
[gcode_macro NEXT]
gcode:
     m876 S2
[gcode_macro CANCEL]
gcode:
     m876 S1

[gcode_macro EXTRACT]
gcode:
     m876 S3

######guided filament change######################################u
######this is supposed to be the version for Fluidd######################################u
############################################u

#------------------------------------------------------u
# MOM - My Overpowered M600 macro / written by Jay Lexx
# Also tenderly called the Mother Of Macros by u/Woodcat64  
# Listen to MOM and everything will be alright!
#------------------------------------------------------
#  NO RESPONSE TAKEN FOR ANY DAMAGE CAUSED BY MOM ;)
#------------------------------------------------------
# 
#
# 09.11.2021 v0.1.6
#
# Sourcecode maintenance due to Klipper updates.
#
# v0.1.5
#
# - added ability to prevent nozzle cooldown
#
# Save this file f.e. as /home/pi/klipper_config/m600.cfg to leave printer.cfg nice and clean
# then use [include /home/pi/klipper_config/M600.cfg] in your printer.cfg
# Don't forget to configure default values in [gcode_makro m600cfg] down below
# 
#
# Usage in CURA Slicer:
# Extensions > Post Processing > Modify G-Code
#	Add a script -> Filament Change
#			Set Layer to value at which filament should be changed
#			I personally set the rest to 0, works like a charm
#			( Tbh, i even didn't check if they have any effect ) 
#
# The M600 command can also be used to just change filament from console or via Button, so, 
# no more need for Unload,Park, Load etc. Macros anymore. The macro should return to the temp
# the printer had when it was started, regardless ff printer temperature at 0, 40 or 200
# It will check if temperature is high enough to extrude filament ( you have configured your 
# min_extrude_temp in printer.cfg [extruder] didn't you ?!?), if not it will use the default 
# temperature configured down below anyway.
# 
#
# If the printer was not homed - therefore not knowing where it is - it will perform 
# a G28 homing sequence . This will ( better say should ;) ) not happen mid print, don't worry. 
# 
# -----------------------------------------------------
#  DESIGNED TO WORK ESPECIALLY WITH OCTOPRINT
# -----------------------------------------------------
# In Octoprint set Plugins -> Printer Dialogs -> Enable Support = Always
# Thx to u/josolanes for mentioning the fix for this possible issue
#
# Please apologize my english, i'm not a native speaker :)
#
# Those macros are in the magic box:
#
# [M876 S]
# Handle prompt response ( to communicate with octoprint )
#
# [JOBCENTER]
# Handles navigation inside the whole process ( better not to issue as terminal command )
#
# [M125]
# Park head
#
# [M701]
# Load filament
#
# [M702]
# Unload filament
#
# [LOW_TEMP_CHECK T]
# Heatup process & temperature processor
# uses printer.cfg [extruder] section max_temp & min_extrude_temp
#
# [M600]
# Marlin compatible guided Filament Change

#-------------------------------------------------------------------------

# Delete sections [respond] and [pause_resume] if already in your printer.cfg
# Both are needed to make MOM run the household and use social media ;)
#-------------------------------------------------------------------------

[pause_resume]
recover_velocity: 100
#   When capture/restore is enabled, the speed at which to return to
#   the captured position (in mm/s). Default is 50.0 mm/s.

[respond]
#default_type: echo
#   Sets the default prefix of the "M118" and "RESPOND" output to one
#   of the following:
#       echo: "echo: " (This is the default)
#       command: "// "
#       error: "!! "
#default_prefix: echo:
#   Directly sets the default prefix. If present, this value will
#   override the "default_type".

#-------------------------------------------------------------------------

#####################
[gcode_macro m600cfg]
#####################

# CONFIGURE YOUR PREFERRED DEFAULT VALUES INSIDE THIS GCODE_MACRO
# Couldn't find anywhere if or how it's possible to define a config section
# Would have been much nicer to deal with, maybe one day i'll find out :)
# Leave me a hint if you know how.

variable_default_temp: 220
# Default temperature to heat up if M600 issued in terminal
# Ignored if a target temperature is already set at launch ( M104 / M109 )
# or started within a printjob

variable_cooldown: 1
# Wether the hotende should cool down or not when pause started
# 1 - Hotend cools down when paused ( Recommended for security reasons and saves some energy if 
#     you're away a longer period of time and therefore can't change the filament)
# 0 - Hotend stays hot ( Not recommended, you never know... )

variable_x: 300
variable_y: 150
# Coordinates to park hotend at (as absolute values)

variable_z: 10
# mm to raise z from current height (this is a relative value!)

variable_zmin: 70
# if current z height is below zmin (as an absolute value), head will lift zmin ( as relative value) instead z
# making it easier to clean the nozzle at that height

variable_load_fast: 6
# mm to load filament at fast speed (length of bowden-hotend-purge)

variable_load_slow: 1
# mm to load filament after fast speed slowly into the hotend incl. purge

variable_bowden: 25
# total mm to unload filament (all at high speed)

variable_speed_1: 6000
# Speed at which filament is loaded/unloaded

variable_speed_2: 9000
# Speed at which hotend is moved to park position

variable_purge: 20
# Possibility to extract xx mm filament after loading if loading was too short f.e.

variable_output: 118
#Additional output send via M117 or M118

# !-ATTENTION--------------------------------------------------------!
# !								     !
# ! Uncomment the desired language / Comment ( Delete ) the other    !
# ! If you edit the language please don't use special characters     !
# ! like Ü,Ö,Ä, Ǣ or É in your language,macro will not work and show !
# ! a UnicodeDecodeError: 'ascii' ... 		                     !
# !------------------------------------------------------------------!

# Textdata HTML UI deutsch (german)
#variable_step_a1: "<CENTER><P><B>SCHRITT 1/3 </B></P><H2>ZEIT ZU WECHSELN</H2>"
#variable_step_b1:"Achtung, der Druckkopf ist ggfs. heiss!<dl><dt>"
#variable_step_c1:"Die Temperatur wurde zur Sicherheit auf 0 gesetzt<dl><dt>"
#variable_step_d1:"Klicke <b>WEITER</B> um (wieder) aufzuheizen<BR> Klipper wird anschliessend das Filament entladen<BR><BR>"

#variable_step_2: "<CENTER><P><B>SCHRITT 2/3</B></P><B>Lade jetzt das neue Filament und klicke auf WEITER<BR><BR>( +/- 10mm in den PTFE Schlauch)"
#variable_step_3: "<CENTER><P><B>SCHRITT 3/3</B></P><B>Reinige den Druckkopf, klicke dann WEITER um mit dem Druck fortzufahren oder ZURUECK um zum vorherigen Schritt 2 zu gelangen."
#variable_next: "WEITER"
#variable_previous: "ZURUECK"
#variable_cancel: "ABBRUCH"
#variable_purgetext: "EXTRAHIERE"

# Textdata HTML UI english
variable_step_a1: "<CENTER><P><B>STEP 1/3 </B></P><H2>TIME TO CHANGE</H2>"
variable_step_b1:"Beware, the nozzle could be hot! <dl><dt>"
variable_step_c1:"Temperature set to 0 for security reasons<dl><dt>"
variable_step_d1:"Click <b>NEXT</B> to heat up (again)<BR> Klipper will then unload the filament<BR><BR>"
variable_step_2: "<CENTER><P><B>STEP 2/3</B></P><B>Load the new filament and click NEXT<BR><BR>( +/- 10mm into PTFE tube)"
variable_step_3: "<CENTER><P><B>STEP 3/3</B></P><B>Wipe nozzle clean, then click NEXT to resume print or click BACK to unload again and return to step 2"
variable_next: "NEXT"
variable_previous: "BACK"
variable_cancel: "CANCEL"
variable_purgetext: "EXTRACT"
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

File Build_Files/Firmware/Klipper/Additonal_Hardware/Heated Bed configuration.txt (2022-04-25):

The Rhino utilizes multiple heated silicon mats on a single aluminum heat spreader to ensure that heat is evenly distributed during the build process.  Unlike systems from other manufacturers the multiple heate mats are meant to work in unison but still retain the ability to be heated separately.  This is due to the range of build plate materials available and those materials having a tendancy to warp due to heat fluctuations.  Because of this we developed a simple macro to control the heaing sequence of all the beds. 

Note these variables will change for setup when altering this macro for your setup.
Heater_Bed0........Left Heater Mat
Heater_Bed2........Right Heater Mat
Heater_Bed.........Default Heater Bed Parameter

Place in start gcode after heated temp has been set!

[gcode_macro BEDMIMIC]
gcode:
  SET_HEATER_TEMPERATURE HEATER=Heater_Bed2 TARGET={printer.heater_bed.target}
  SET_HEATER_TEMPERATURE HEATER=Heater_Bed0 TARGET={printer.heater_bed.target}

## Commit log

2022-01-12 Add files via upload
    These are preliminary printer.cfg files, all working. Setup requires BTT SKR GTR, MKS Rumba, BTT Tango, along with other various addon boards that will be detailed in future literature.
    [printer Jack Rabbit.cfg, printer Laser.cfg, printer-spindle.cfg]
2022-03-28 Create 4pin Fan Wiring & Klipper configuration
2022-03-28 Rename ESC.txt to Klipper ESC configuration & Wiring.txt.txt
    [Klipper ESC configuration & Wiring.txt.txt]
2022-03-28 Create Heated Bed configuration.txt
    [Heated Bed configuration.txt]
2022-04-25 Update Heated Bed configuration.txt
    [Heated Bed configuration.txt]
2022-04-25 Add files via upload
    neopixel macro and pin assignments need placed
    [3dp.cfg, client_macros.cfg, laser.cfg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]
2022-04-26 Rename Firmware/Klipper/printer (2).cfg to Firmware/Klipper/Config_Files/printer.cfg
    [printer.cfg]
2022-04-26 Rename Klipper ESC configuration & Wiring.txt.txt to Klipper ESC configuration & Wiring.txt
    [Klipper ESC configuration & Wiring.txt]
2022-04-26 Rename Firmware/Klipper/4pin Fan Wiring & Klipper configuration to Firmware/Klipper/Additonal_Hardware/4pin Fan Wiring & Klipper configuration
2022-04-26 Rename Firmware/Klipper/Klipper ESC configuration & Wiring.txt to Firmware/Klipper/Additonal_Hardware/Klipper ESC configuration & Wiring.txt
    [Klipper ESC configuration & Wiring.txt]
2022-04-26 Rename Firmware/Klipper/Heated Bed configuration.txt to Firmware/Klipper/Additonal_Hardware/Heated Bed configuration.txt
    [Heated Bed configuration.txt]
2022-04-30 Update 4pin Fan Wiring & Klipper configuration
2022-04-30 Update and rename 4pin Fan Wiring & Klipper configuration to 4pin Fan Wiring & Klipper configuration.md
2022-11-03 Update and rename Z-Axis_Components.md to Readme.md
2023-01-09 Create Laserweb Setup.md
2023-03-31 Rename Firmware/Klipper/Macros_&_Addons/Tool Idenfication.md to Firmware/Klipper/Macros_&_Addons/Tooling ID/Tool Idenfication.md
2023-04-12 Rename ACP_Panels/Control Panel-Left.step to Build_files/ACP_Panels/Control Panel-Left.step
    [Control Panel-Left.step]
2023-04-12 Rename ACP_Panels/Control Panel-Right.step to Build_Files/ACP_Panels/Control Panel-Right.step
    [Control Panel-Right.step]
2023-04-12 Rename ACP_Panels/Front Inner Panel v4.step to Build_Files/ACP_Panels/Front Inner Panel v4.step
    [Front Inner Panel v4.step]
2023-04-12 Organized Files
    [15mm idler bottom.step, 15mm idler top.step, 3dp.cfg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]
2023-04-14 Update
    Update of XY Joiners and Upload of New Drag Knife holder design.
    [Left XY Bottom.step, Left XY Top.step, Ostrich Drag Knife.step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]
2023-04-14 Add literature for gantry
2026-10-07 Reorganize the repo and bring it up to date
    New layout: frame/ (with panels), motion/xy, motion/z, bed/, toolheads/,
    electrical/, filament-box/, docs/, archive/. Files moved with git mv so
    their history follows them.
    - New README with banner, toolhead line art, features, folder map and roadmap
    - Toolheads renamed to current names: blockone (new, ready for build files),
    switchfly, lightsaber (was Laser_Mount), hotjoe (was Spindle), dragknife
    (was Ostrich Drag Knife); Jack Rabbit kept as legacy
    - A page per toolhead: picture, files, 21W4 connector pins, macros
    - Electrical: BTT Octopus replaces the SKR GTR notes; wiring diagrams added;
    old pin assignment PDF removed
    - 2023 Klipper firmw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
    [15mm idler bottom.step, 15mm idler top.step, 3dp.cfg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]
2026-10-07 Z axis: 2:1 belt reduction; LightSaber is 80 W
    Claude-Session: https://claude.ai/code/session_017RrB3Xvn879FhMmsWe16ZW

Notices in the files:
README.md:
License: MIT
